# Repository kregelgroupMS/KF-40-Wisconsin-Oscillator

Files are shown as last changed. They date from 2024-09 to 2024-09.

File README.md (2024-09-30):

This repository contains the materials needed to construct the KF 40 Wisconsin Oscillator circuit as described in this JASMS publication.
We intend this information to be freely available for academic researchers and students, but any entity intending to use these materials in a for-profit manner must contact the authors and receive permission for their use.

If you are interested in the original implementation of the Wisconsin Oscillator, please see follow this link for fabrication files and instructions: https://github.com/uw-madison-chem-shops/wisconsin-oscillator 

For questions, please contact us at sjkregel@fsmail.bradley.edu

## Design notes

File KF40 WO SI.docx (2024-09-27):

Assembly Instructions for the KF40 Wisconsin Oscillator

This document details the assembly procedures for the KF40 integrated Wisconsin Oscillator circuit. Fabrication files for the two printed circuit boards are included in the Supplemental Information as Gerber files, and a 3D model of the assembly jig is included as a .STEP file. We recommend using a 3D printer to create the assembly jig but machining a metal jig would also be a viable option.

1) Place the upper board face down in the center of the assembly jig and apply solder paste evenly around the back contact ring.

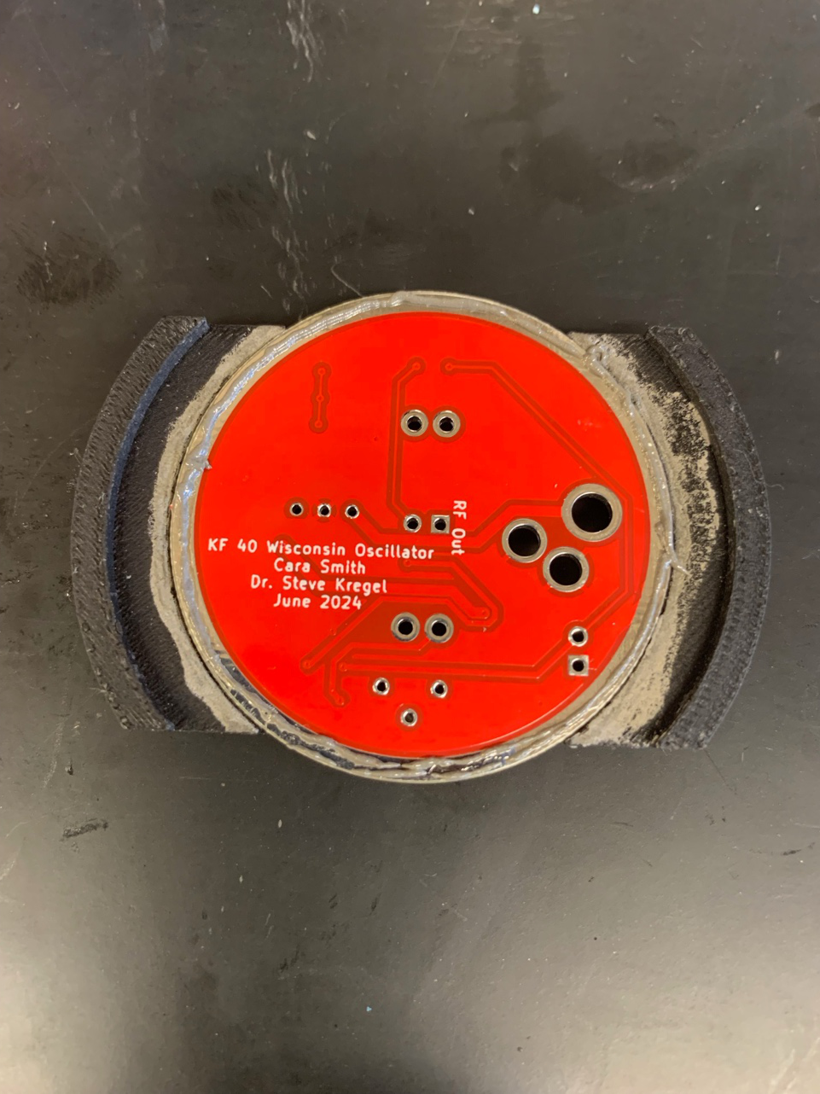
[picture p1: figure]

Figure S1. The upper ring placed upside down in the assembly jig. Solder paste has been applied around the outside conductive contact for joining to the lower ring.

2) Place the lower ring PCB into the assembly jig and secure with metal binder clips. The clips must be metal as they will hold the assembly together in the toaster oven and will melt if plastic.

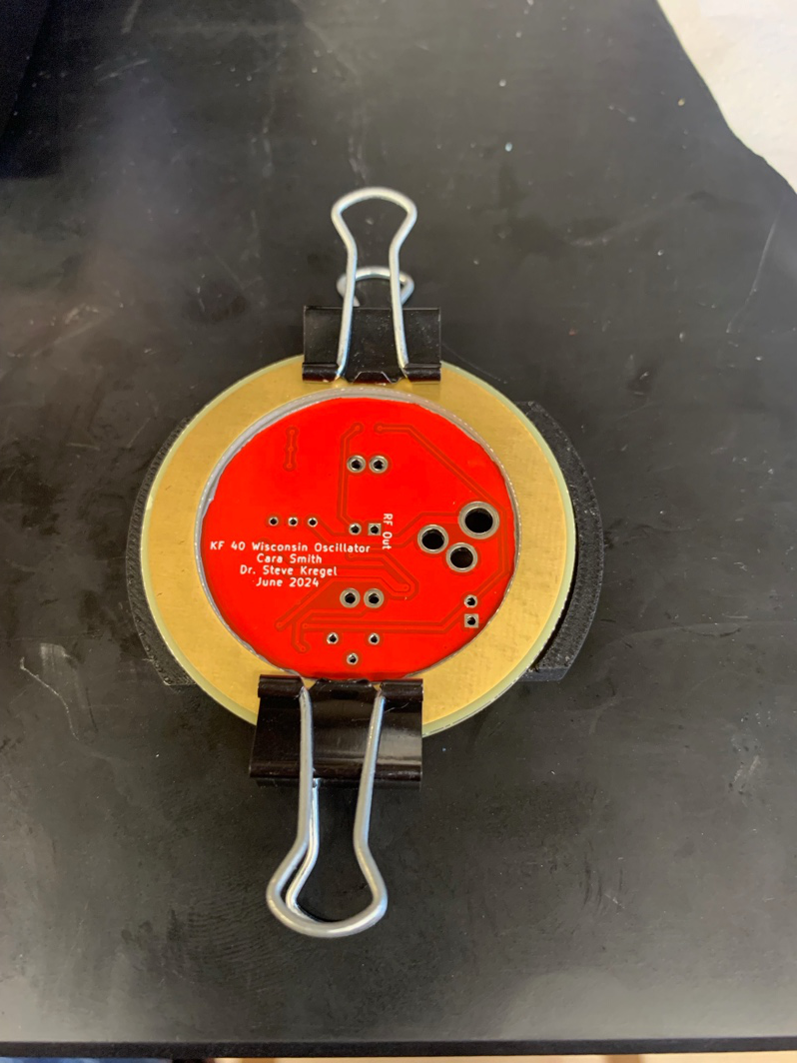
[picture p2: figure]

Figure S2. The lower ring is placed in the assembly jig on top of the upper ring, and the two PCB’s are secured together with binder clips.

3) Remove the aligned PCB’s from the assembly jig and apply solder paste to the contact pads for U1-U4 as well as the electrolytic capacitor C5.

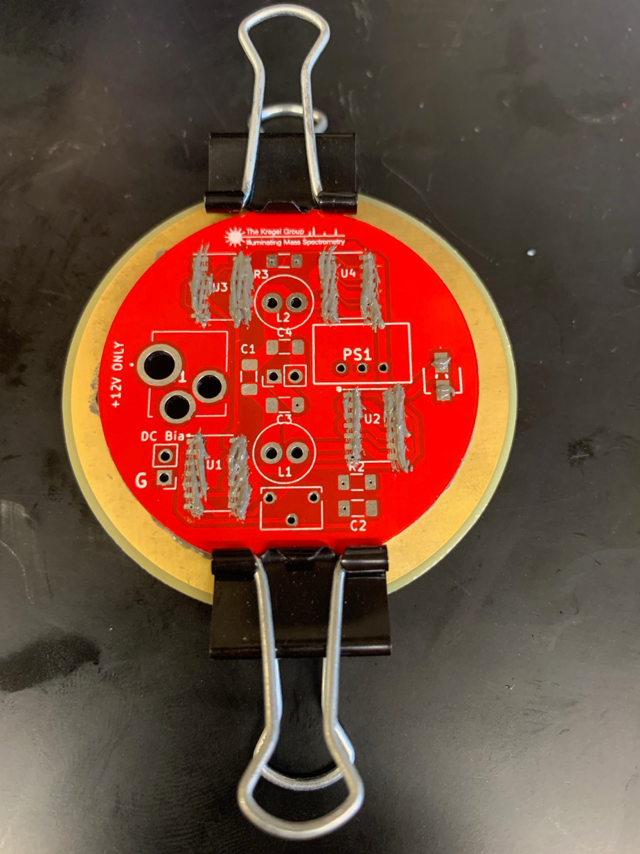
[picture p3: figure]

Figure S3. The clamped PCB assembly is removed from the assembly jig and solder paste is applied to the connections for U1-U4, as well as C5.

4) Populate U1-U4 and C6 with the appropriate components and place the entire assembly into a toaster oven to melt the solder paste. We use a toaster oven in leu of a proper solder re-flow oven due to the vastly reduced costs. We typically set our toaster oven to ~200C on the “air-fry” setting for about 7 minutes, or until the solder paste has melted completely. The entire assembly is then removed from the oven and allowed to cool before removing the metal binder clips. Following this process the oscillator vacuum flange should look similar to Figure #. Puddles of solder paste around the edge of the upper board are expected and generally pose no issues for mounting the assembly to the vacuum chamber. Note: it is critical to use this solder re-flow process to properly seal the vias present in the pads of the inverter chips U1-U4.

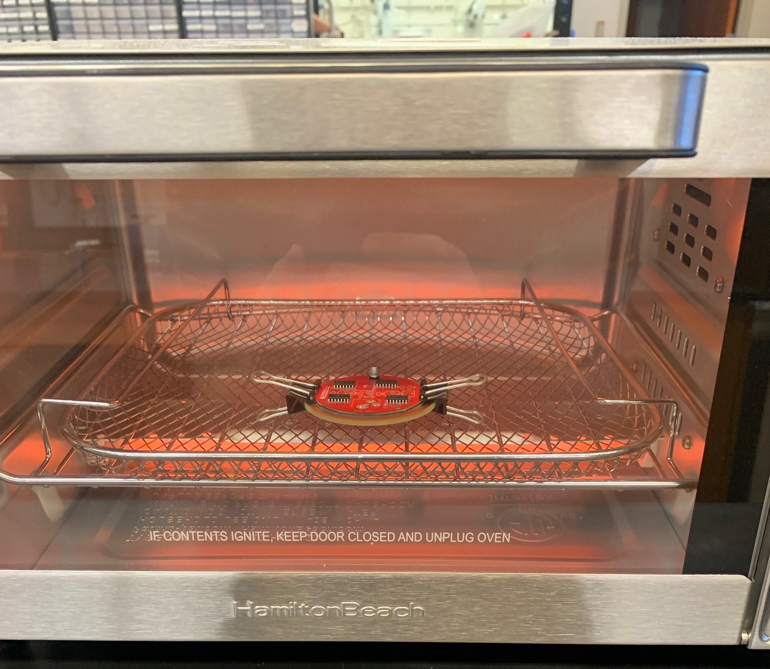
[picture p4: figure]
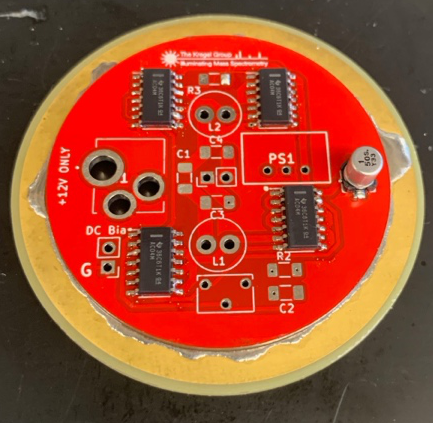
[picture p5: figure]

Figure S4. Top: U1-U4 and C5 are populated with the appropriate components, and the entire PCB assembly is placed into the toaster oven for reflow soldering. Bottom: The PCB assembly following reflow soldering. Some solder has leaked out from between the two PCBs. A small amount of leakage is acceptable, provided it does not interfere with the bulkhead clamps when mounting the assembly to the vacuum chamber.

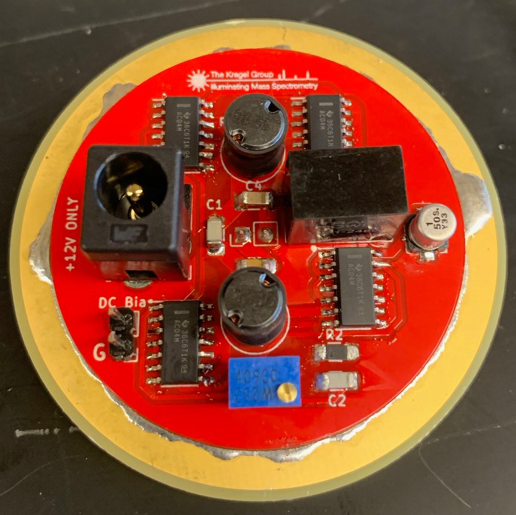
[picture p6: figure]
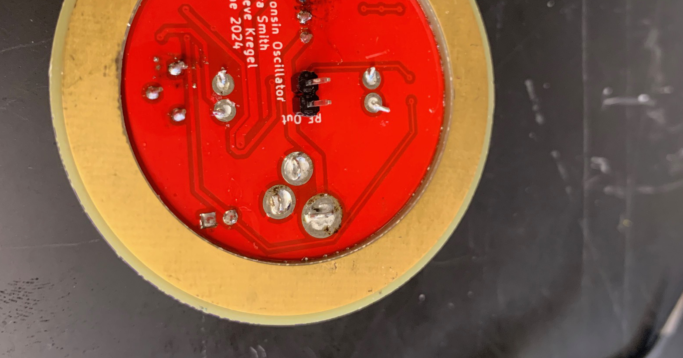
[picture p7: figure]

5) Solder the remainder of the components onto the upper board. For the surface mount components, this is optionally done in conjunction with step 4 above, but we find it easier to ensure proper placement if done separately. In the toaster oven the assembly rests on the rounded legs of the metal binder clips. This instability tends to tilt the assembly and cause the smaller surface mount components to shift during the re-flow process. Note: the central pin header J1, should be soldered in “backwards” so that the pins extrude into the vacuum chamber when the oscillator flange is mounted to the vacuum chamber.

Figure S5. Left: Assembled KF40 Wisconsin Oscillator from the air side of the flange. Right: The vacuum side of the same oscillator. Note that the RF output pin header extends into the vacuum for internal electrical connection.

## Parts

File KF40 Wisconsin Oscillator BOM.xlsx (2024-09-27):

Reference | Description | Quantity | Mouser PN
C1 | 10pF 1000V | 1 | 791-SH31N100J102CT
C2 | 2.2pF 1000V | 1 | 791-1206N2R2C102CT
C3, C4 | 4700pF | 2 | 710-885342208020
C5 | 1uF 50V Electrolytic | 1 | 667-EEE-1HA010NR
L1, L2 | Inductor (Multiple Values) | 2 | See Below (The values of L1 and L2 must be equal to obtain a balanced output)
U1-U4 | CD74AC04M96 | 4 | 595-CD74AC04M96
RV1 | 50kOhm Potentiometer | 1 | 652-3266Z-1-503LF
R2, R3 | 1MOhm | 2 | 71-CRCW12061M00JNEAC
PS1 | 6.5V DC/DC Converter | 1 | 495-TSR-1-2465
J1 | Barrel Jack Connector | 1 | 710-694106402002
J2 | DC Bias Input Pin Header | 1 | 649-1012937890201BLF
J3 | RF Output Pin Header | 1 | 649-1012937890201BLF
Different values of inductors can be used to control the output frequency based on the capacitive load.
We use the 2200R series of inductors from Murata power solutions due to the high Q-factors of these inductors and the wide availability of different inductance values.
Inductance (uH) | Mouser PN
10 | 580-22R103C
15 | 580-22R153C
22 | 580-22R223C
33 | 580-22R333C
47 | 580-22R473C
68 | 580-22R683C
100 | 580-22R104C
150 | 580-22R154C

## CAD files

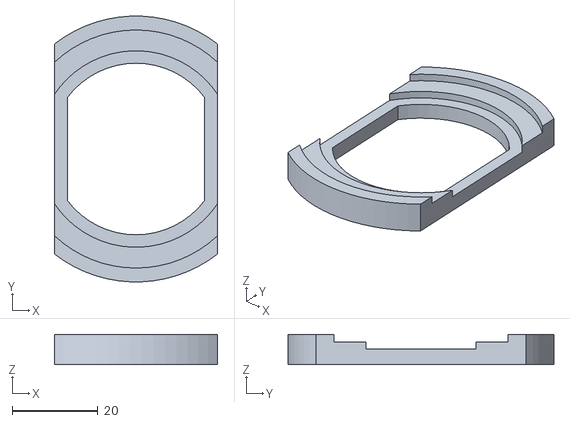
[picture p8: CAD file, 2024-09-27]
KF40 Wisconsin Oscillator Assembly Jig.STL
38.0 x 61.9 x 7.00

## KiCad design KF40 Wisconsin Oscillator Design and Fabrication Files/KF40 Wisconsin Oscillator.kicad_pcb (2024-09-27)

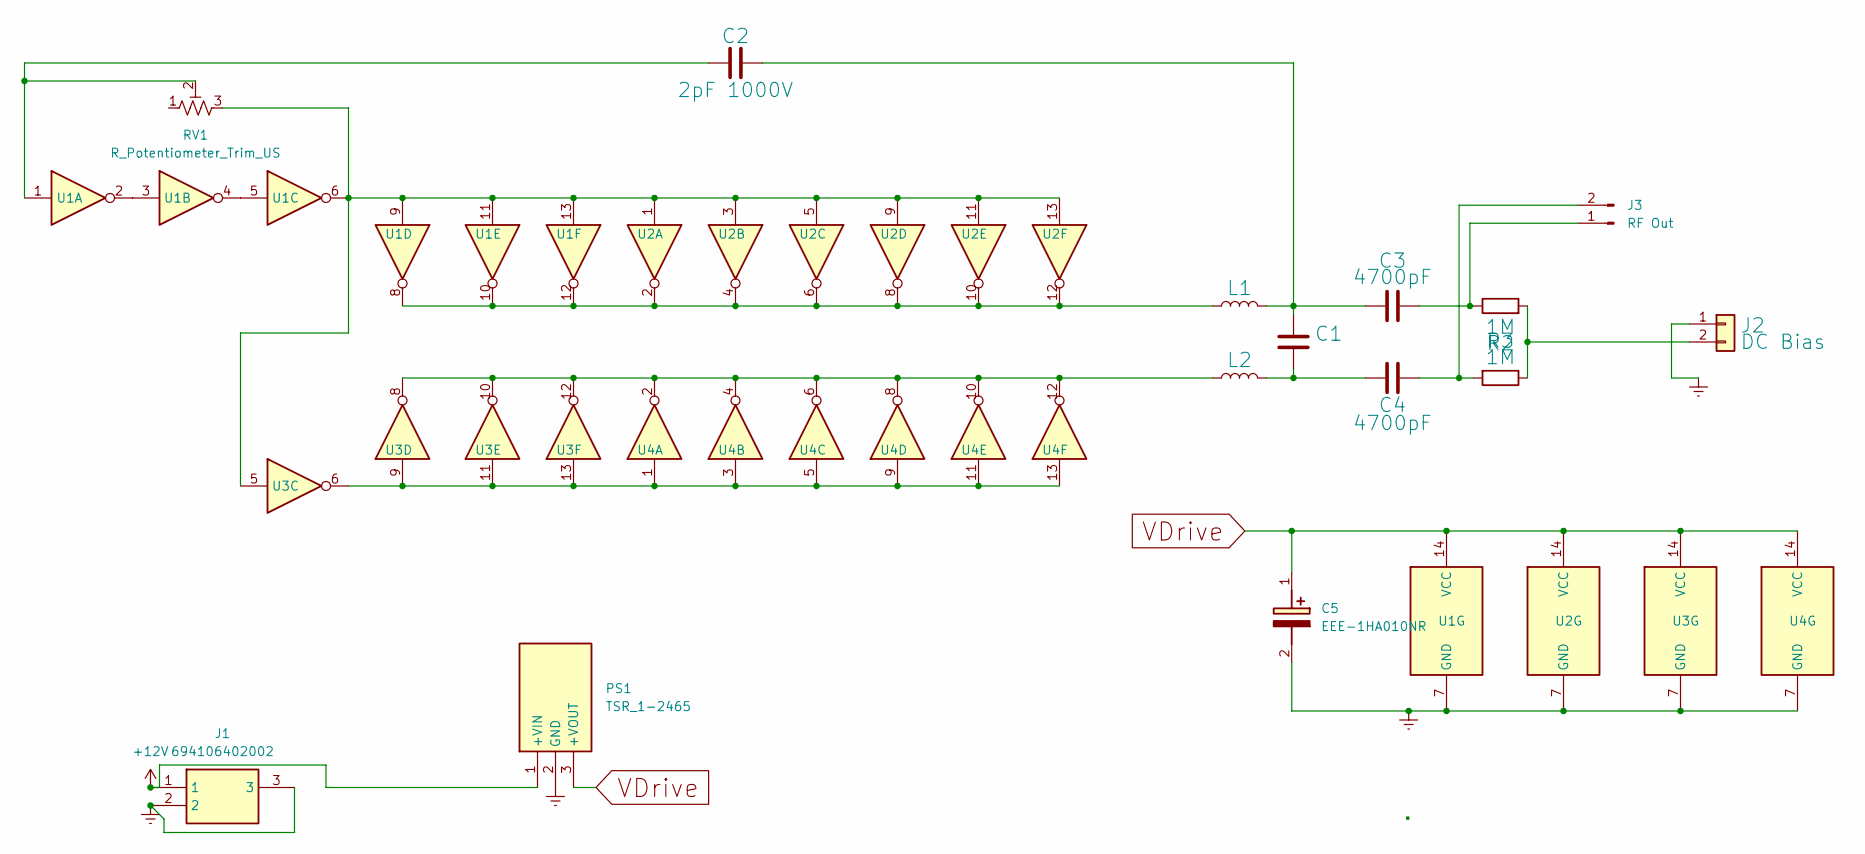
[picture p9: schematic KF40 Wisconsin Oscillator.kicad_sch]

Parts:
C1: 1000V; C_1206_3216Metric_Pad1.33x1.80mm_HandSolder
C2: 2pF 1000V; C_1206_3216Metric_Pad1.33x1.80mm_HandSolder
C3, C4: 4700pF; C_1206_3216Metric_Pad1.33x1.80mm_HandSolder
C5: EEE-1HA010NR; EEE1AA220WR; Manufacturer_Part_Number EEE-1HA010NR; Mouser Part Number 667-EEE-1HA010NR
J1: 694106402002; Manufacturer_Part_Number 694106402002; Mouser Part Number 710-694106402002
J2: DC Bias; PinHeader_1x02_P2.54mm_Vertical
J3: RF Out; PinHeader_1x02_P2.54mm_Vertical
L1, L2: 150uH (22R154C); L_Radial_D7.0mm_P3.00mm
PS1: TSR_1-2465; TSR-1-2433; Manufacturer_Part_Number TSR 1-2465; Mouser Part Number 495-TSR-1-2465
R2, R3: 1M; R_1206_3216Metric_Pad1.30x1.75mm_HandSolder
RV1: R_Potentiometer_Trim_US; Potentiometer_Bourns_3266W_Vertical
U1, U2, U3, U4: CD74AC04M96; SOIC-14_3.9x8.7mm_P1.27mm

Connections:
+12V: J1.1, PS1.1 (+VIN)
Earth: C5.2 (-), J1.2, J1.3, J2.1, PS1.2 (GND), U1.7 (GND), U2.7 (GND), U3.7 (GND), U4.7 (GND)
unnamed: C1.1, C2.2, C3.2, L1.2
unnamed: C1.2, C4.1, L2.2
unnamed: C2.1, RV1.2, U1.1
unnamed: J2.2, R2.2, R3.1
unnamed: C3.1, J3.1, R2.1
unnamed: C4.2, J3.2, R3.2
unnamed: L1.1, U1.8, U1.10, U1.12, U2.2, U2.4, U2.6, U2.8, U2.10, U2.12
unnamed: L2.1, U3.8, U3.10, U3.12, U4.2, U4.4, U4.6, U4.8, U4.10, U4.12
unnamed: RV1.3, U1.6, U1.9, U1.11, U1.13, U2.1, U2.3, U2.5, U2.9, U2.11, U2.13, U3.5
unnamed: U1.2, U1.3
unnamed: U1.4, U1.5
unnamed: U3.6, U3.9, U3.11, U3.13, U4.1, U4.3, U4.5, U4.9, U4.11, U4.13
VDrive: C5.1 (+), PS1.3 (+VOUT), U1.14 (VCC), U2.14 (VCC), U3.14 (VCC), U4.14 (VCC)

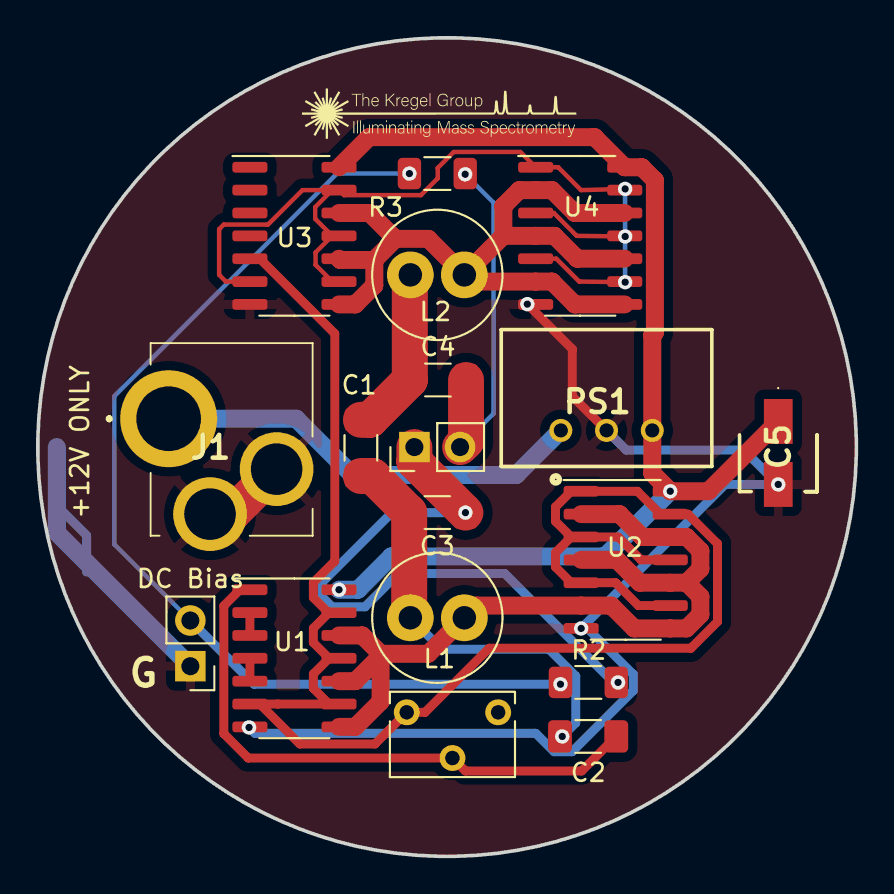
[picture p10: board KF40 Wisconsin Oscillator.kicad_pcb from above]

Board: 2 copper layers, 45.5 x 45.5 mm, 18 parts (0 on the bottom side), 15 nets.
